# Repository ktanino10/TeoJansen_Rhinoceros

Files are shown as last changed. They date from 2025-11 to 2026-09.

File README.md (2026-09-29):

# Theo Jansen “Rhinoceros” — Ver.3.1 and prototype records

[English](README.md) | [日本語](README_ja.md)

**Website:** [English](https://ktanino10.github.io/TeoJansen_Rhinoceros/en/) · [日本語](https://ktanino10.github.io/TeoJansen_Rhinoceros/)

**Documents:** [English documents and Japanese counterparts](docs/README_en.md) · [How to use / resource legend](docs/USER_GUIDE_en.md). CAD and numerical data are shared; the original Ver.1 PDF drawings remain Japanese.

## Ver.3.1 — Current design

[Current comparison, 360° and 12-stage assembly](https://ktanino10.github.io/TeoJansen_Rhinoceros/en/r7.html) · [Continuous walking display and English videos](https://ktanino10.github.io/TeoJansen_Rhinoceros/en/walking.html) · [Current CAD / STEP / STL / BOM downloads](https://ktanino10.github.io/TeoJansen_Rhinoceros/en/index.html#downloads)

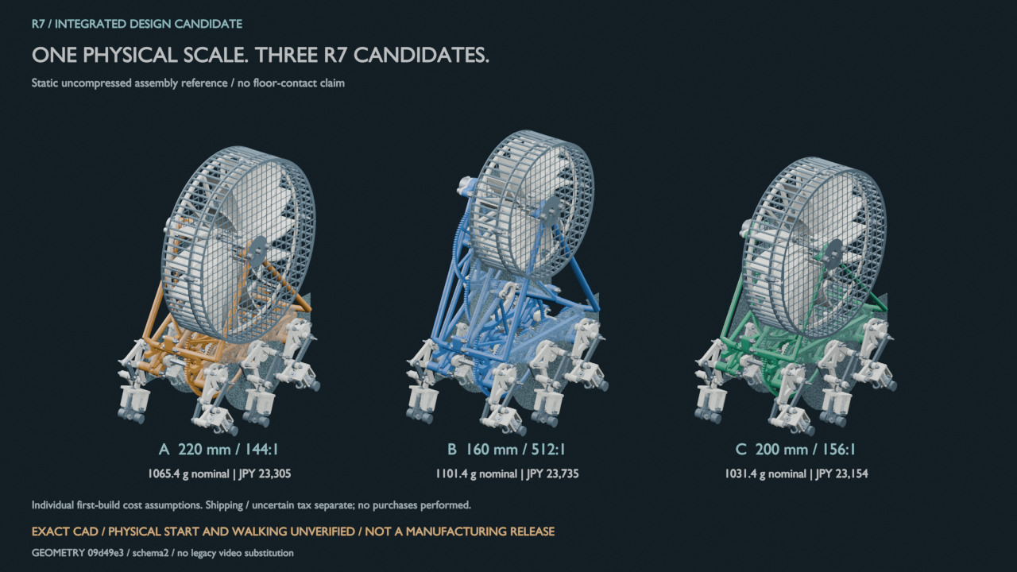
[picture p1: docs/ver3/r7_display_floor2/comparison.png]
Ver.3.1 floor-corrected A, B and C at the same scale; CAD rendering, not a physical build


**Ver.3.1 is the public name of the existing floor-corrected design, not a new mechanical revision.** Engineering ID: `v3-integrated-walkers-r7-16-floor2`; immutable artifact/source commits and hashes remain in [the source contract](site/r7-source.json). [Design and BOM index](docs/ver3/integrated_r7/README_en.md) · [Assembly](docs/ver3/integrated_r7/ASSEMBLY_en.md) · [Floor correction](docs/ver3/integrated_r7/FLOOR_CORRECTION_en.md) · [Separately versioned walking model](docs/ver3/r7_walking_v1/MODEL_en.md).

`manufacturingRelease=false`, physically qualified count 0; real wind, self-starting and physical 30 cm walking remain UNKNOWN. Seven representative slicing inspections are not whole-machine print/fit qualification. Walking uses prescribed 120 rpm input and 16× time compression, not measured performance. Existing r7 labels inside media refer to this Ver.3.1 geometry; canonical results, nulls and BOMs are unchanged.

**Version guide:** Ver.1/2 = historical physical builds; [Ver.3.0 = initial concepts, archived CAD and videos](https://ktanino10.github.io/TeoJansen_Rhinoceros/en/comparison.html); Ver.3.1 = current design. Internal r2/r3/r4/r6 study IDs are not public product versions. The build log below preserves the historical Ver.1/2 account.

---
## Repository Contents

```text
TeoJansen_Rhinoceros/
├── Fusion360/          # Fusion 360 design files (.f3d)
├── STL/                # 3D printable parts (STL files)
├── docs/               # Additional documentation and images
│   └── images/         # Photos and diagrams
├── README.md           # This file (English)
└── README_ja.md        # Japanese documentation
```



---

## Background

I first discovered Theo Jansen’s *Strandbeest* on YouTube and was captivated by the beauty of its wind-powered, organic motion.  
At the same time, I became fascinated by its internal mechanisms and thought: *“I want to try recreating this with my own hands.”*

Rather than making a perfect replica, I wanted to incorporate **more mechanical aesthetics and my own design preferences**.  
In particular, I love the design of the **ν (Nu) Gundam**, so I drew inspiration from its **color scheme** and **structural nuances** for this project.

For those unfamiliar with the Nu Gundam, here’s the official promotional video used as a design reference for part of this build:

<a href="https://youtu.be/TQ98cSiHVVs?si=otUml2E1TVQzA8v8" target="_blank">
  Nu Gundam official promo video thumbnail
</a>

---

## How to Use This Repository (Overview)

This “Rhinoceros” has evolved through multiple iterations from **Ver.1 to Ver.2**.  
While there is no fully detailed step-by-step manual, I believe you can build it by referencing the PDFs and animations below.

Each version includes the corresponding **STL files**.  
If you’re attempting this for the first time, I recommend starting by understanding the structure and motion of **Ver.1**.

I’ve also summarized my personal build log (as far as I can recall) in the following sections.

| Version | Summary | Drawings | Videos |
|---|---|---|---|
| Ver.1 | Initial design modeled in Fusion 360 | 1. [TeoJansen_2D_v1.pdf](./docs/テオヤンセン2Dv1.pdf)<br>2. [TeoJansen_2D_latest.pdf](./docs/テオヤンセン2D図面最新.pdf) | 1. [Assembly Video](https://youtu.be/Q7d0sq1SNJ0?si=nhAsBmjNhFsv74Ju)<br>2. [Motion Simulation](https://www.youtube.com/watch?v=RxUTcOTfPt0) |
| Ver.2 | Improved: 150% scale with more stable operation |  | 1. [First Motion Test](https://youtu.be/T3U7c1Mr3Y8?si=hUQZJXoczCW0qAUG)<br>2. [Overview / Re-verification](https://youtu.be/JzXOxTJvHzw?si=1MGZkGYogJQsFP-6) |

- **FYI**: This model is also published on Bambu Lab’s community platform [**MakerWorld**](https://makerworld.com/ja/models/1971139-n-gundam-style-strandbeest-ver-2).

---

# Ver.1 Build Process

## 1. Research
I observed YouTube videos and various images to infer and understand the structure and operating principles.  
Since many makers have shared their works worldwide, **web research and video viewing** are extremely helpful.

<a href="https://youtu.be/MYGJ9jrbpvg?si=qMYy9t26JGlFZo1x" target="_blank">
  Theo Jansen Strandbeest YouTube thumbnail
</a>

---

## 2. Design
All parts were 3D-modeled in Autodesk **Fusion 360**.  
In the early phase, I mainly traced shapes while closely observing real works;  
I performed little to no detailed mechanics calculations at that stage.

Because of that choice, I ended up iterating many rounds of prototyping and fine-tuning later—  
this became one of the most time-consuming and labor-intensive stages.  
Please treat the following drawing as **one reference among many**, not a strict blueprint.

### 📄 **Ver.1 2D Drawing**  
[TeoJansen_2D_latest.pdf](./docs/テオヤンセン2D図面最新.pdf)

> *Note:* GitHub may not preview PDFs inline. If so, please open them via the link above.

### 🎨 Ver.1 Concept Rendering (Fusion 360)

These are rendered images of Ver.1 in Fusion 360,  
created to verify geometry, structure, colors, and shading *before* actual printing—  
and to visualize the “moving art” concept during the design phase.

---

<div align="center">

| Oblique View | Front View | Side View |
|---|---|---|
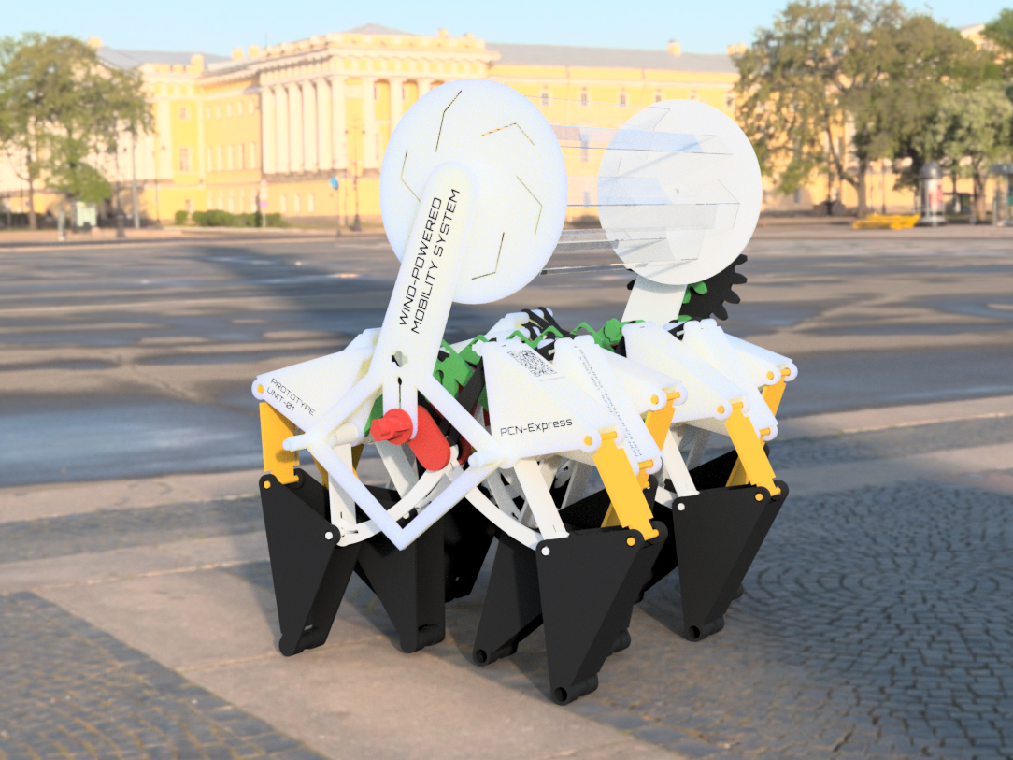
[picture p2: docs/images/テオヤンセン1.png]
Oblique view
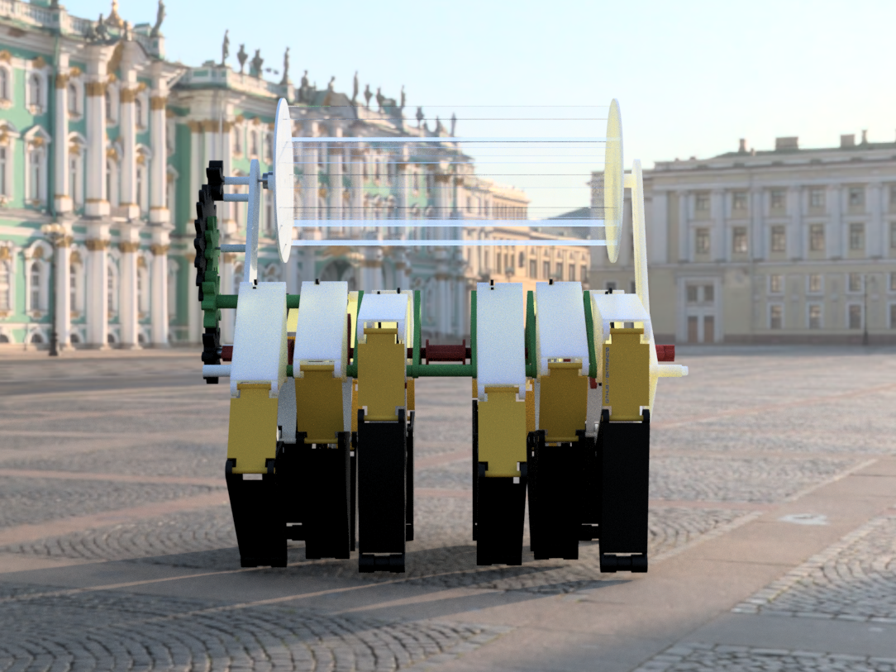
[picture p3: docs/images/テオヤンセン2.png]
Front view
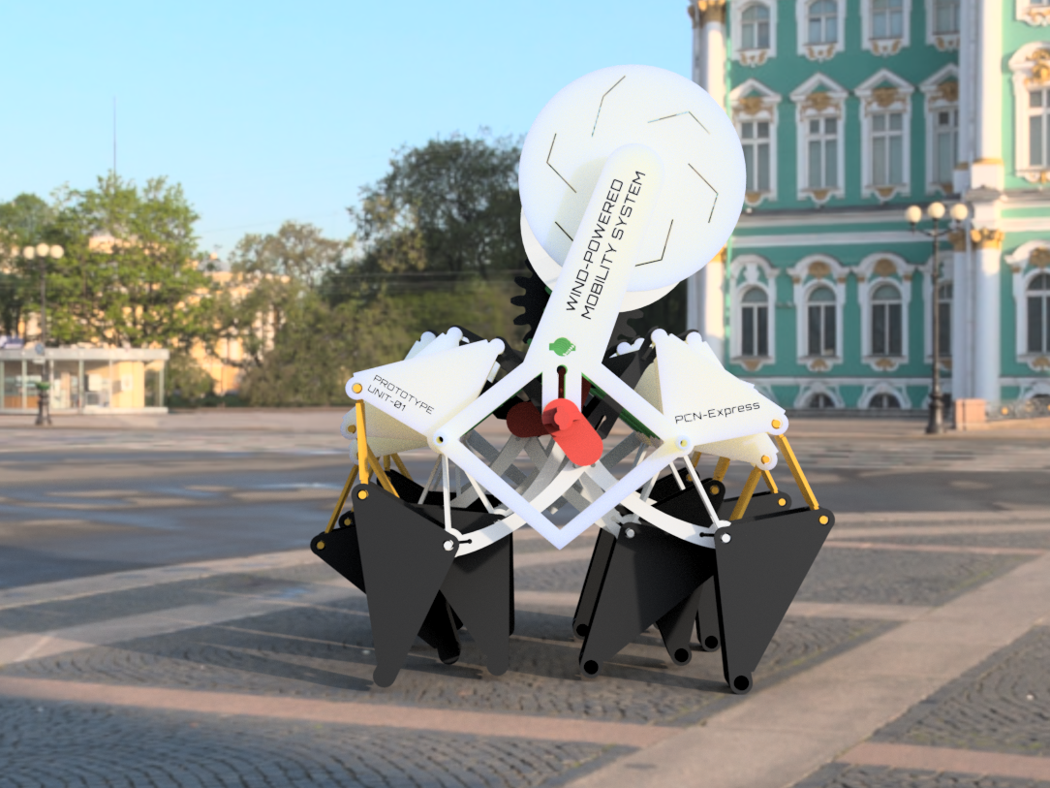
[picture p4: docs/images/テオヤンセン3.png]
Side view
|  |  |  |

| Rear View | Opposite Side | Reverse Oblique |
|---|---|---|
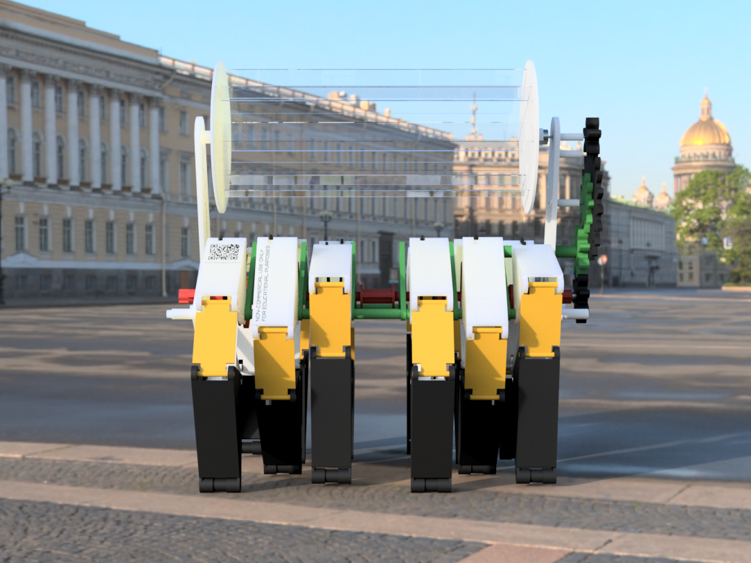
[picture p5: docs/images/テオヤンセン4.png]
Rear view
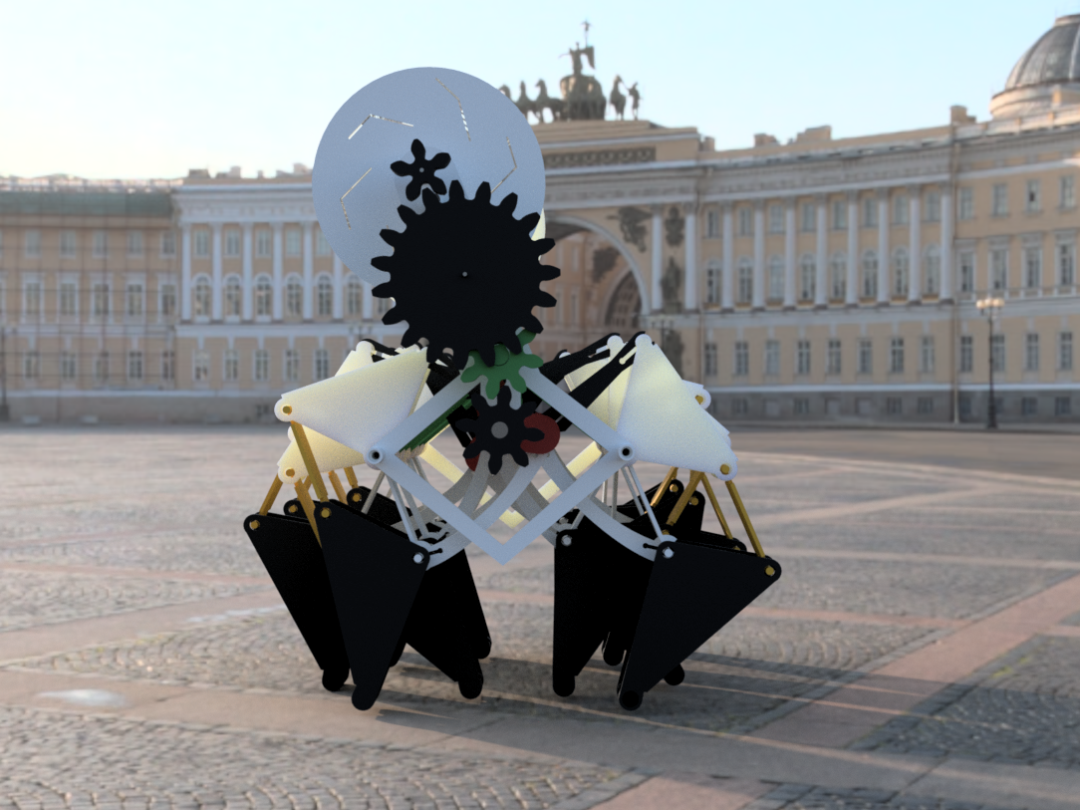
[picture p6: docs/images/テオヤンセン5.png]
Opposite side
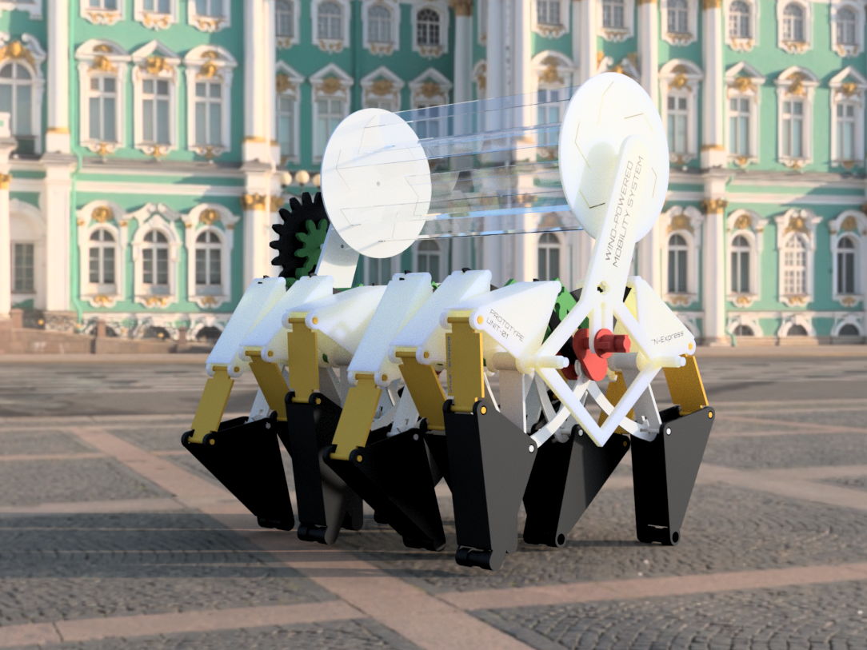
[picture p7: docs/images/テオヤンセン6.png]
Reverse oblique
|  |  |  |

</div>

### 🧩 Ver.1 Assembly Images  
[TeoJansen_2D_v1.pdf](./docs/テオヤンセン2Dv1.pdf)

> *Note:* If PDF preview doesn’t work on GitHub, please open via the link.

**Assembly Video**  
<a href="https://youtu.be/Q7d0sq1SNJ0?si=nhAsBmjNhFsv74Ju" target="_blank">
  Ver.1 Assembly video thumbnail
</a>

### 🦿 Ver.1 Motion Image  
**Simulation Video**  
<a href="https://youtu.be/RxUTcOTfPt0?si=KSsferuiFyFRqOAX" target="_blank">
  Ver.1 Motion Simulation thumbnail
</a>

---

## 3. 3D Printing
I optimized print directions and part splits to balance dimensional accuracy and strength.

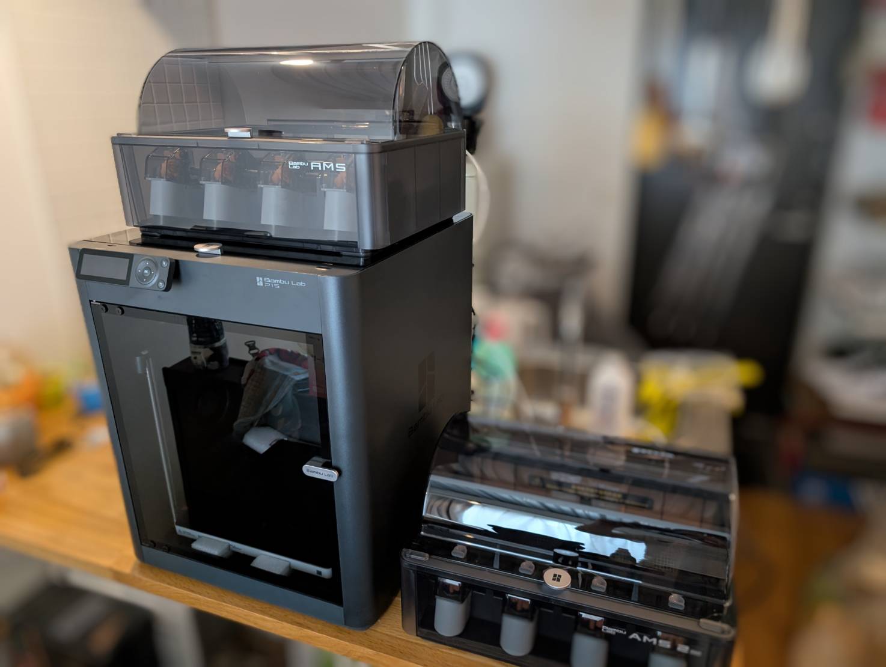
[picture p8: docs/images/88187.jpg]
3D printer in progress


## Recommended Print Settings

- **Scale**: 150% (legs recommended at 160%)  
- **Material**: ABS (also common for Gunpla; heat resistance ~80 °C)  
- **Printer**: Bambu Lab FDM printer  
- **Note 1**: This model is also listed on [**MakerWorld**](https://makerworld.com/ja/models/1971139-n-gundam-style-strandbeest-ver-2).  
- **Note 2**: Depending on geometry, consider **splitting parts and bonding afterward**.  
  Although support is an option, considering **cost and time**, I mainly chose splitting (support kept minimal) except for the crankshaft.

---

🎥 ** Print Video**  
Watch on YouTube (https://www.youtube.com/watch?v=6YfYPoaMa58)

---

## 4. Sanding
Surfaces that contact supports tend to be rough, so I sanded the crankshaft with a power sander.  
By stepping through **#400 → #600 → #800**, I smoothed layer lines for a clean finish.

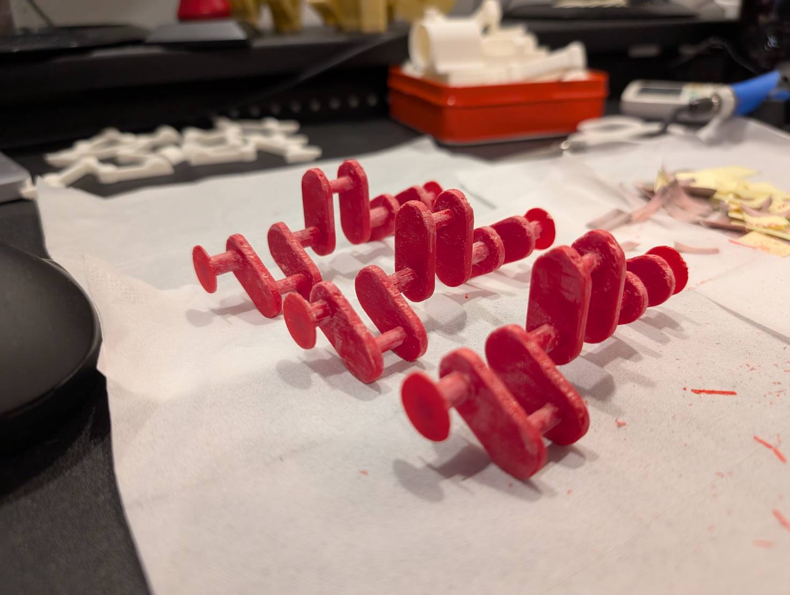
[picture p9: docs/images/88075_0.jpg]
Crankshaft after sanding


🎥 **Sanding Process**  
Watch on YouTube (https://www.youtube.com/watch?v=w-jB8-OUFfA)

---

## 5. Ultrasonic Cleaning
After sanding, I cleaned parts with an **ultrasonic cleaner**.  
Adding a **small amount of detergent** reduces surface tension so bubbles penetrate details and remove fine dust and swarf.

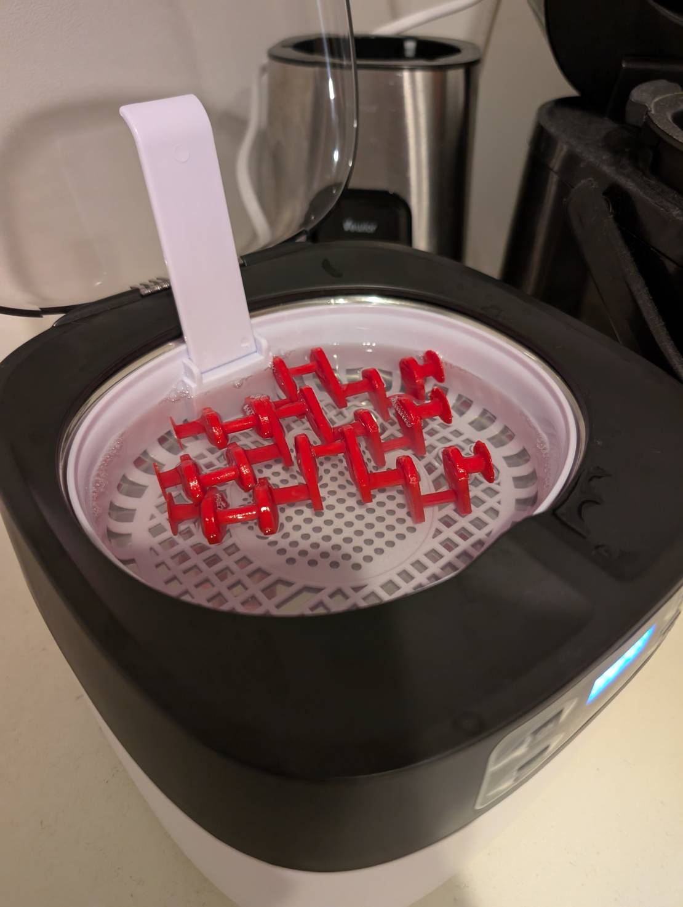
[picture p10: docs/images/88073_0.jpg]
Ultrasonic cleaning


🎥 **Ultrasonic Cleaning Video**  
Watch on YouTube (https://www.youtube.com/watch?v=2DyWBz1phlA)

### 🧴 Bonding After Cleaning
Some parts require **temporary sub-assembly by bonding** after cleaning.  
I used the following adhesive, which bonds ABS strongly and maintains strength after curing:

- **Adhesive**: [Tamiya ABS Cement](https://www.tamiya.com/japan/products/87137/index.html)  
  (Part no. 87137 / 40 ml)

> *Tip:* Waiting about 30 minutes for full cure improves joint stability.

---

## 6. Painting
I airbrushed the parts in a paint booth. Equipment used:

- Airbrush  
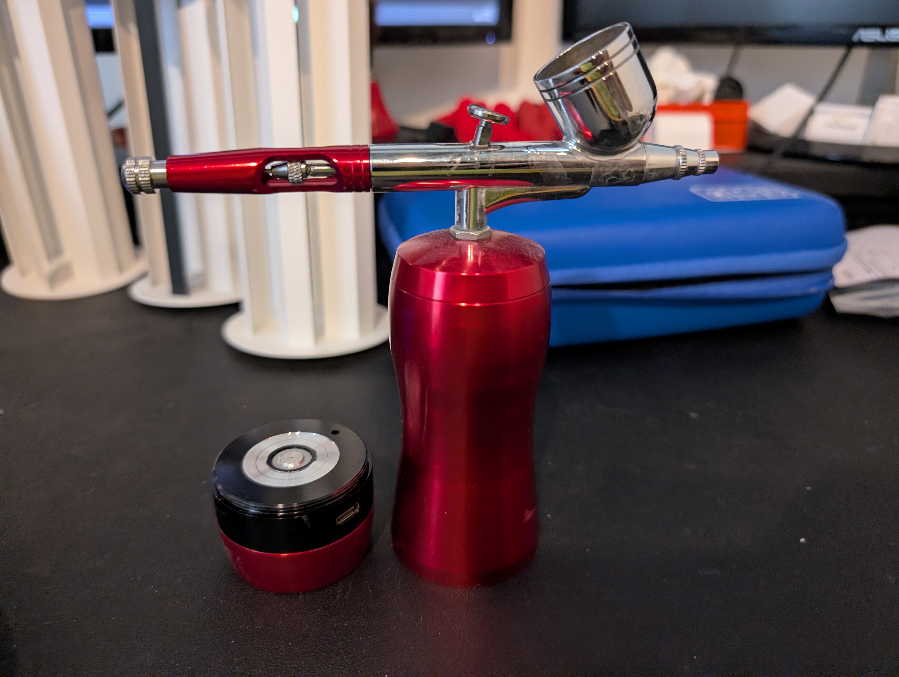
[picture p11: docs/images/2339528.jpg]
Airbrush used
  

- Spray booth  
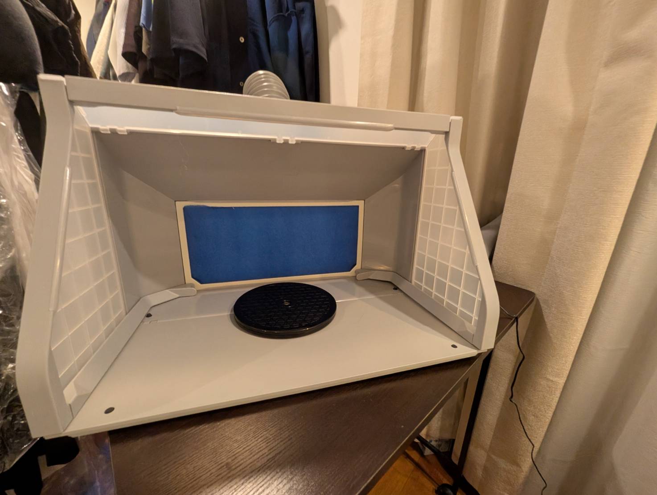
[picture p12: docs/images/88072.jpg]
Spray booth used
  

- For safety, I wore a respirator.  
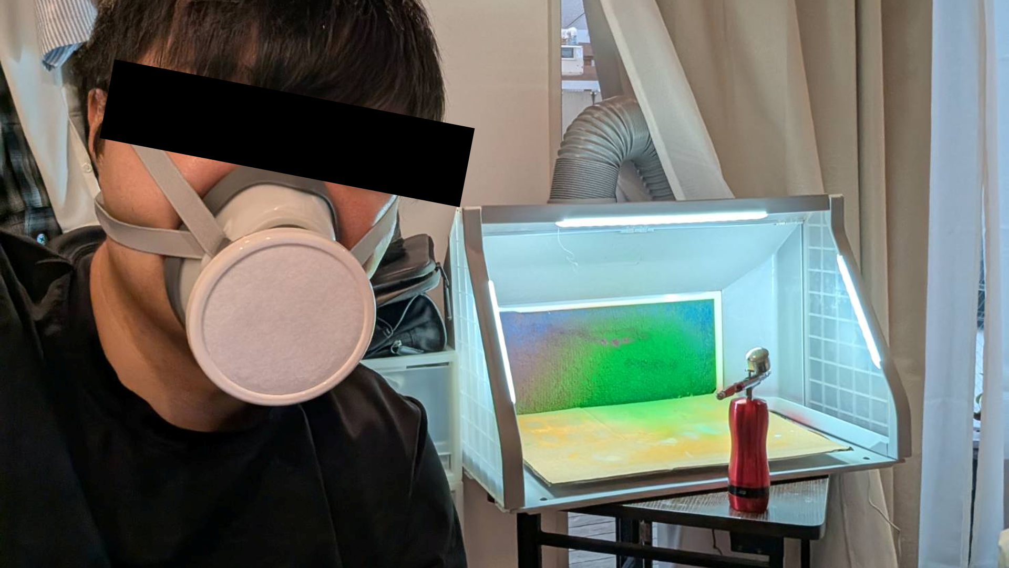
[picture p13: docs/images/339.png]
Respirator mask


- Prep image before painting  
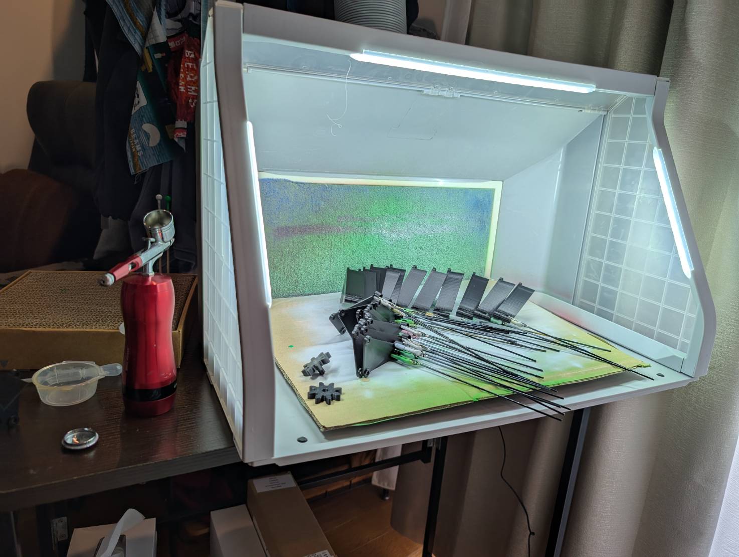
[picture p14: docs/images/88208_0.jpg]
Painted parts
  

### 🎨 Painted Parts
Below are comparisons of pre-/post- sanding, ultrasonic cleaning, and painting.

- Drying painted parts  
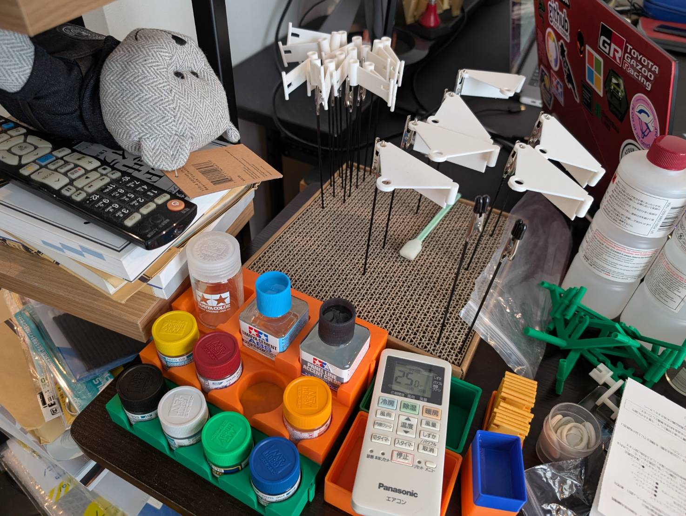
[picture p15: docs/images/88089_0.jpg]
Painted parts drying
  

- Crankshaft finish comparison  
  Left = before processing; Right = after sanding/cleaning/paint.

| View | Left (before: no sanding/cleaning/paint) • Right (after: sanding/cleaning/paint) |
|---|---|
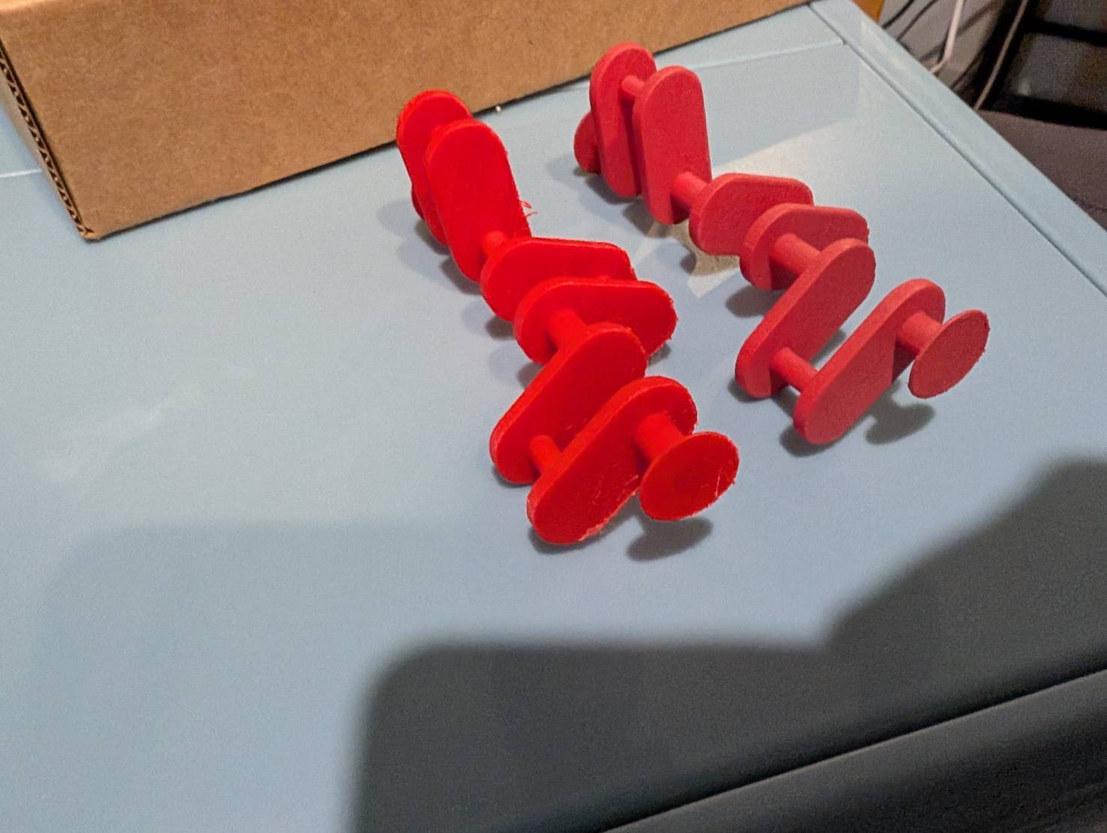
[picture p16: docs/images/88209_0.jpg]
Crankshaft comparison oblique - before
| **Oblique** |  | Crankshaft comparison oblique - after |
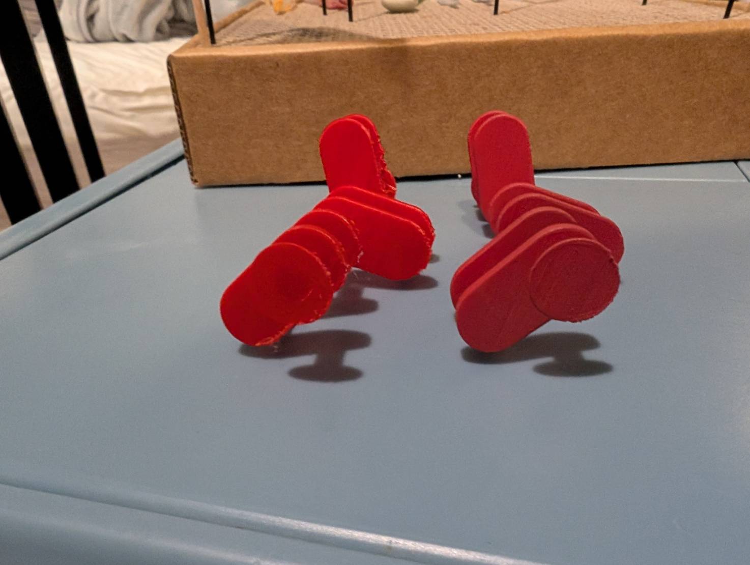
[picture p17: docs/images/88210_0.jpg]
Crankshaft comparison side - before
| **Side** |  | Crankshaft comparison side - after |
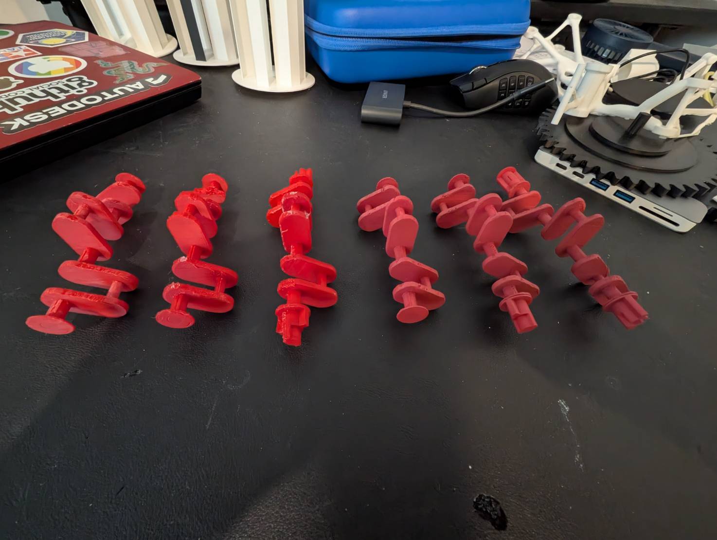
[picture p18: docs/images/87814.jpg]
Crankshaft comparison gradient - before
| **Gradient finish** |  | Crankshaft comparison gradient - after |

---

## 7. Decals
I applied decals with a setting solution, adjusted positions with cotton swabs,  
and finished with a matte topcoat to enhance depth and definition in the details.

### 📸 Decal Application
Below are images taken during and immediately after application:

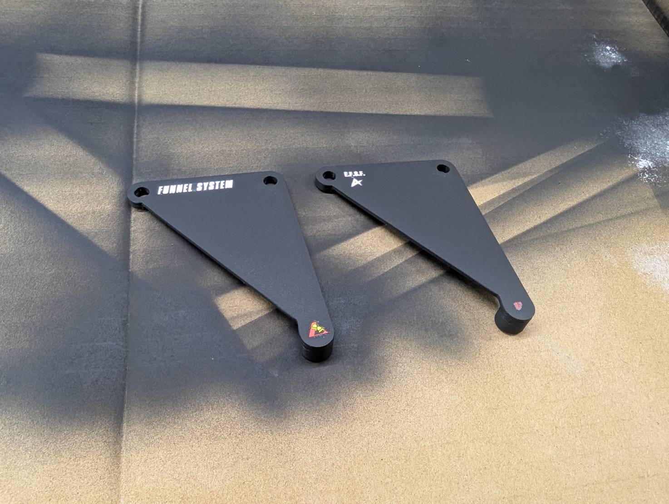
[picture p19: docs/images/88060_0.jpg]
Decal work 1
  
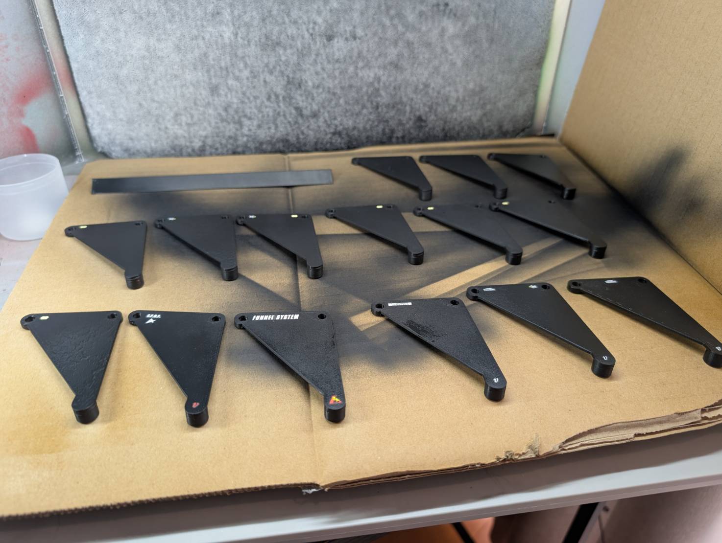
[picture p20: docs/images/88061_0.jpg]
Decal work 2
  
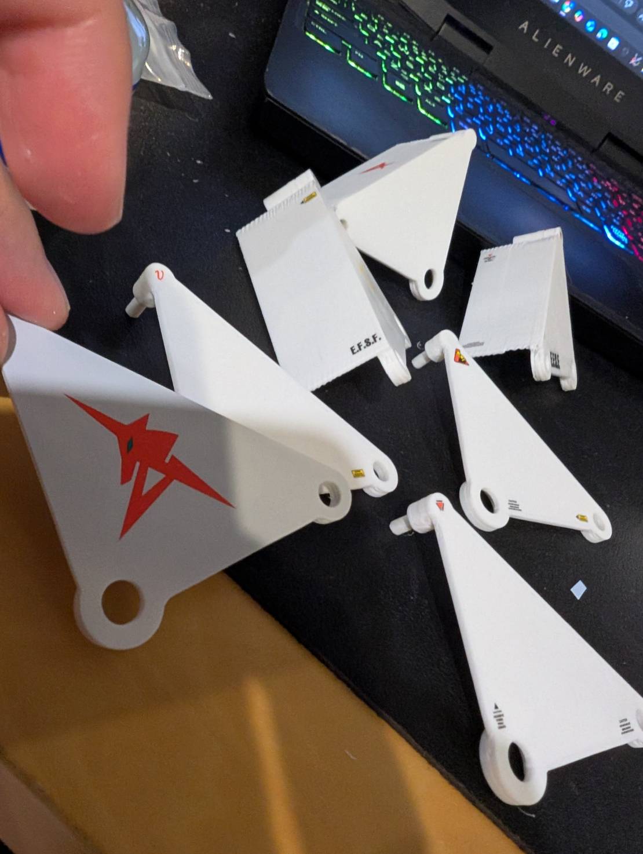
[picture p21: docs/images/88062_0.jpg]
Decal work 3
  
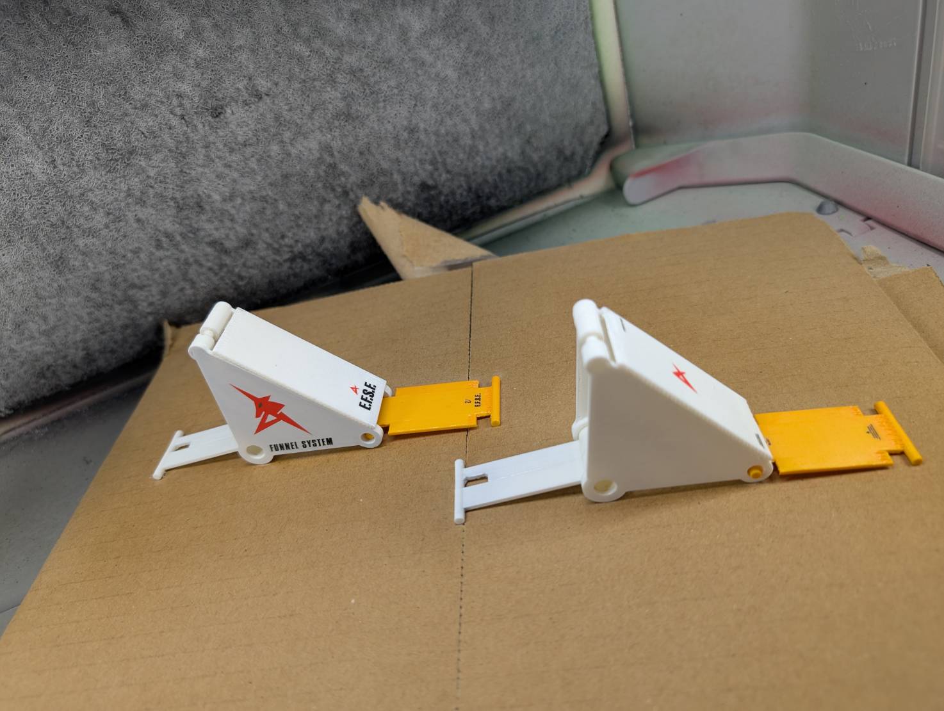
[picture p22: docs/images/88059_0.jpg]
Decal work 4


---

## 8. Ver.1 Final Assembly & Functional Check

I verified gear transmission, crankshaft rotation, and wind-driven motion.  
While aiming for smooth operation overall, several issues were discovered.

For the wind turbine and gear shafts, I used **stainless steel round rods**  
and cut them to length with **metal shears**:

- [Stainless steel rods (Amazon)](https://www.amazon.co.jp/dp/B0FCYMZJF7?ref=ppx_yo2ov_dt_b_fed_asin_title&th=1)  
- [Metal shears (Amazon)](https://www.amazon.co.jp/dp/B0BQB8PLWK?ref=ppx_yo2ov_dt_b_fed_asin_title)

### Ver.1 Exterior (at completion)

<div align="center">

| Oblique | Front | Side |
|---|---|---|
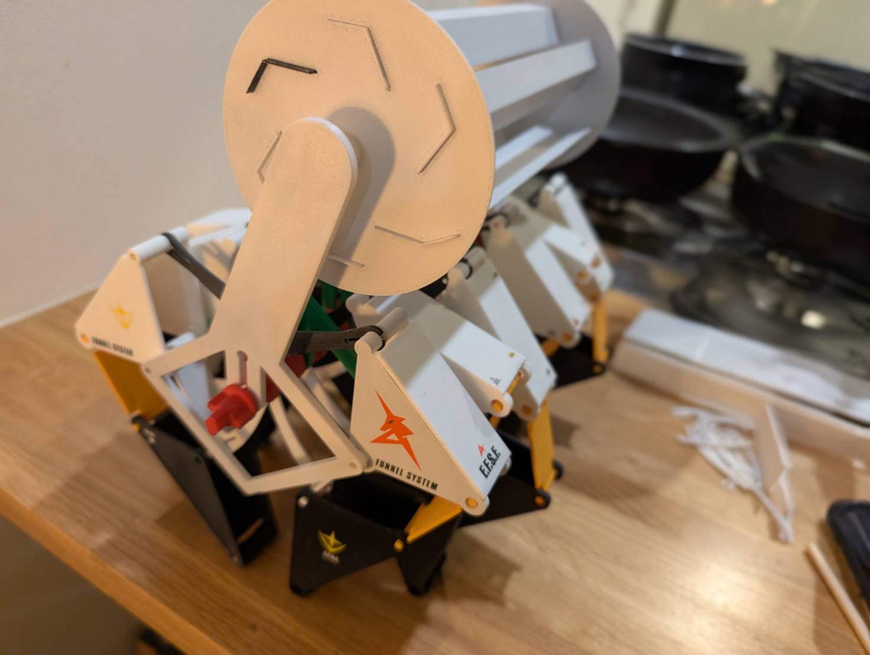
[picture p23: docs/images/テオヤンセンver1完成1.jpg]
Ver1 oblique
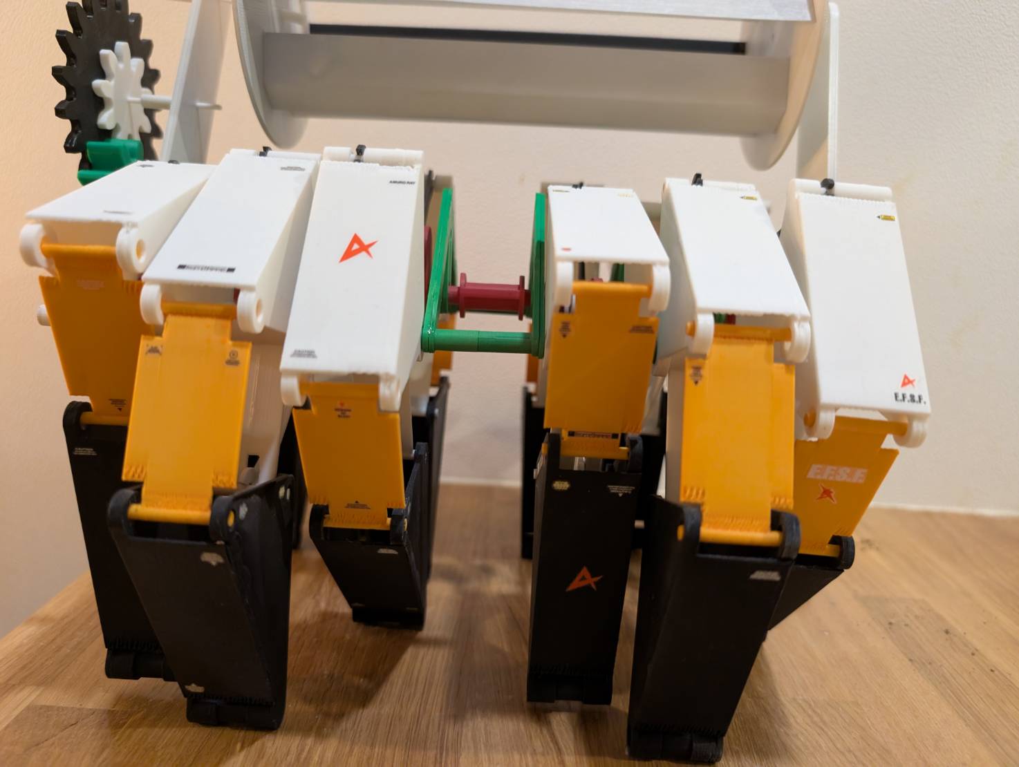
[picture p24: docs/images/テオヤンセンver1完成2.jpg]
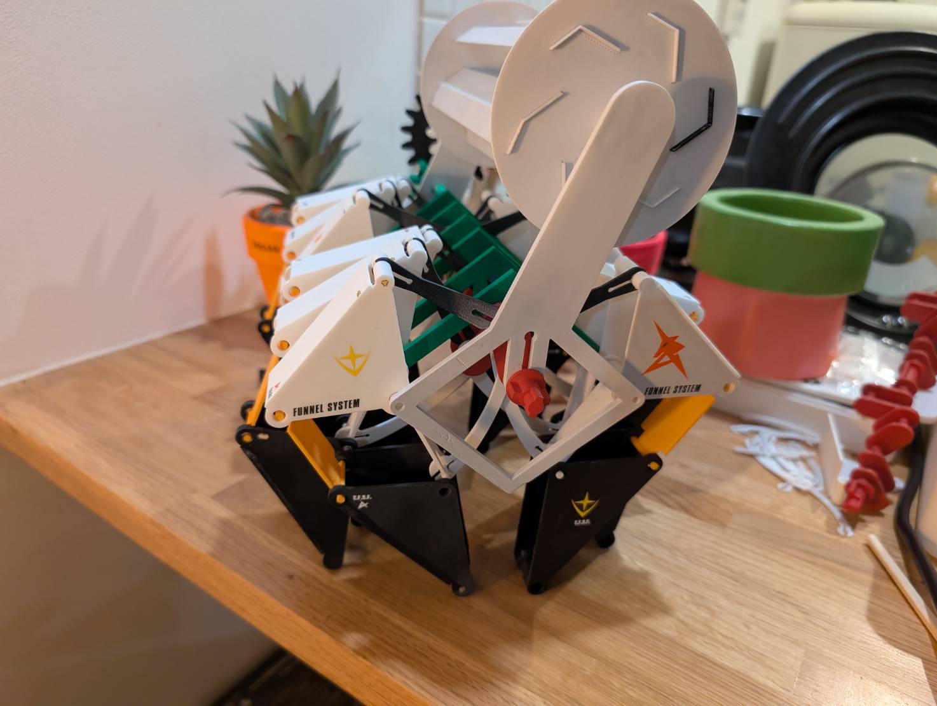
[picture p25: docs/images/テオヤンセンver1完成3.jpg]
|  |  |  |

| Rear | Opposite Side | Reverse Oblique |
|---|---|---|
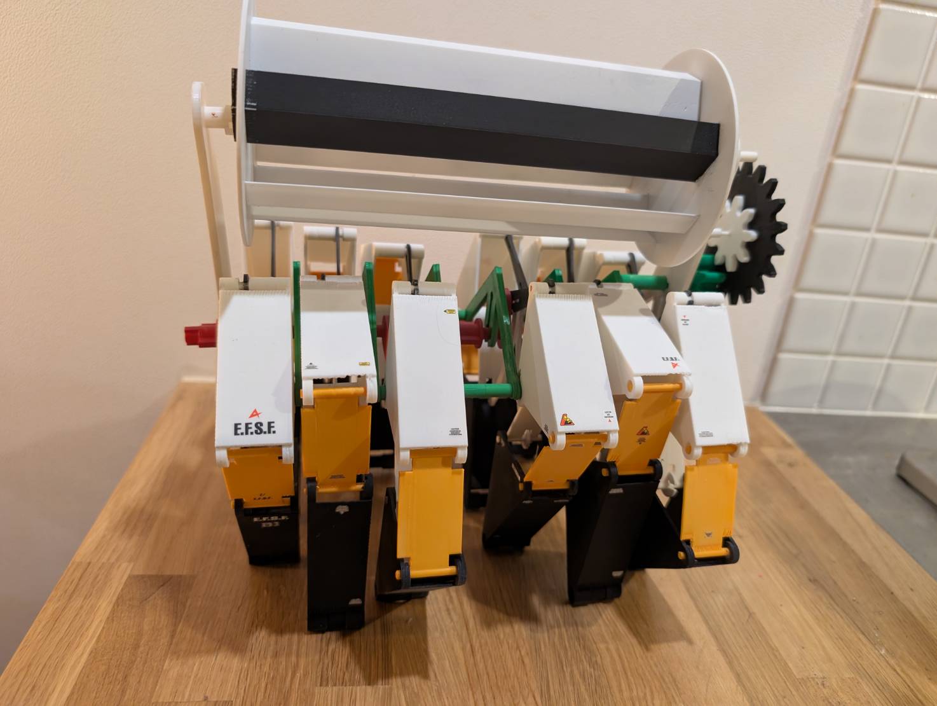
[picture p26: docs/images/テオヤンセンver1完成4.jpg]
Ver1 rear
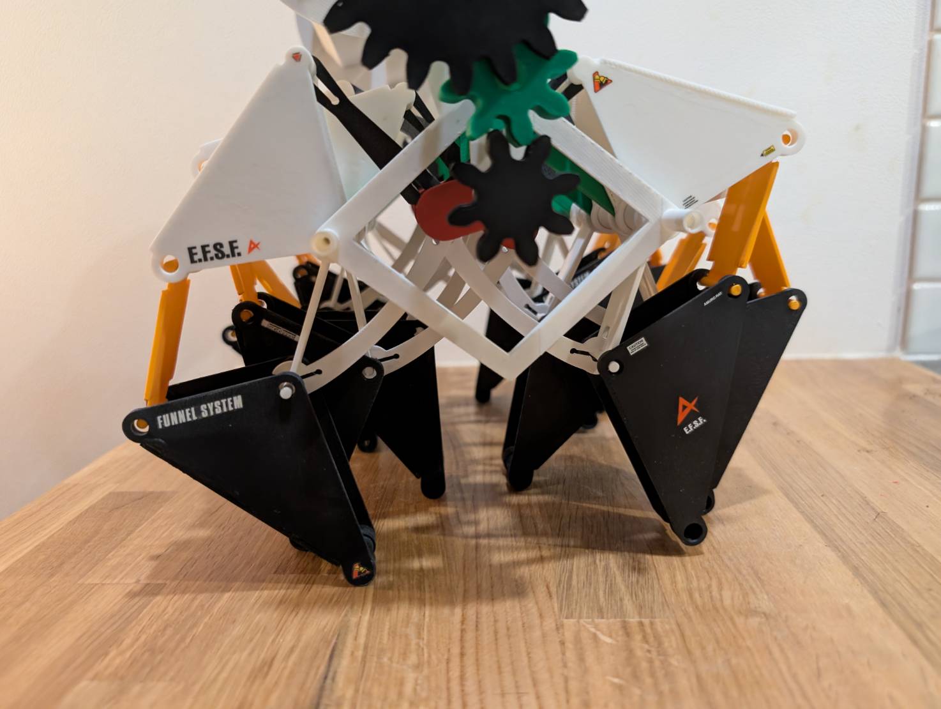
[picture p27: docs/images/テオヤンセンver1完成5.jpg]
Ver1 opposite
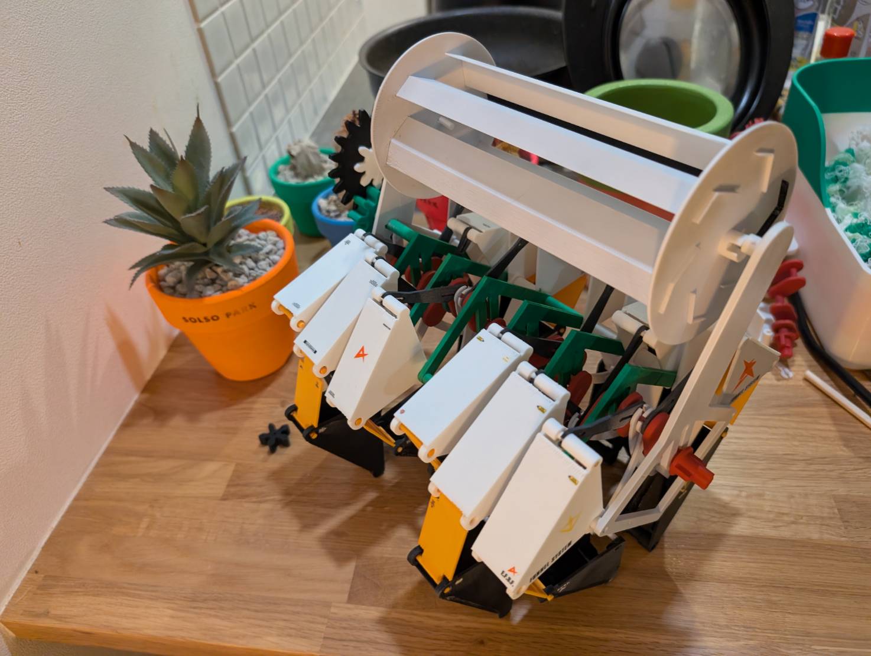
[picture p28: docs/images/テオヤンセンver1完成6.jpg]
Ver1 reverse oblique
|  |  |  |

</div>

### ⚙️ Observed Issues

- The wind turbine did not rotate well under wind power.  
- Some parts popped off during manual rotation.  
- The turbine was unstable and the shaft exhibited wobble.

These findings became key drivers for improvements in Ver.2.

🎥 **Initial Motion Test Video**  
Watch on YouTube (https://youtu.be/Ic3GasmMlio?si=MSvn6-1x6faBUwIh)

---

## 9. Ver.1 Redesign & Structural Improvements

### ⚙️ Main Causes of Ver.1 Failures and Directions for Improvement

Several issues surfaced during Ver.1 prototyping.  
Below are the causes and how I addressed them toward Ver.2.

1) **Gear Ratio Insufficiency**  
The **gear ratio was too small** relative to the crankshaft, yielding insufficient torque from wind power and unstable rotation.

Taking a cue from bicycle gearing (trade-off between force and speed),  
I redesigned the gear train with large–small gear pairs that transmit torque more effectively,  
so the system can move even with low wind input.

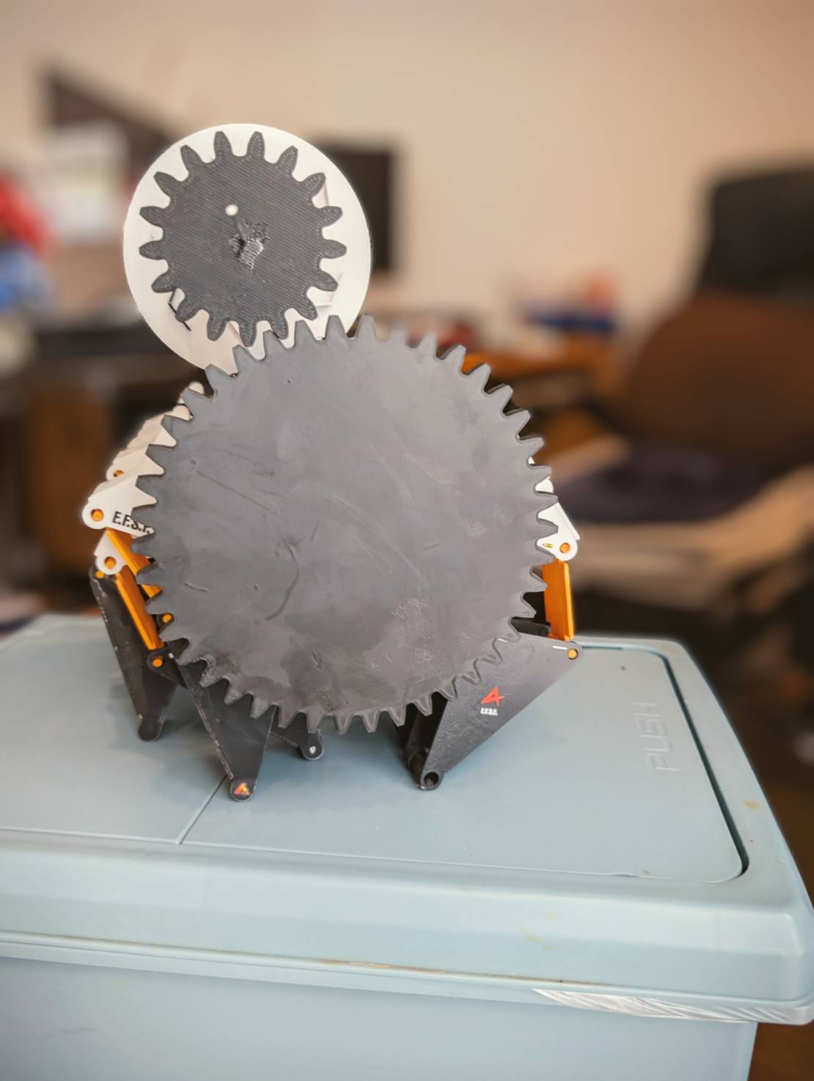
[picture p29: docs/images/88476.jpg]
Gear test 1


> The photo above is an example of ratio tests toward Ver.2.  
Even a simple combination matters when you’re figuring out how to transmit and amplify small forces.

Because gears are **highly modular and combinable**, I explored many patterns for Ver.2:

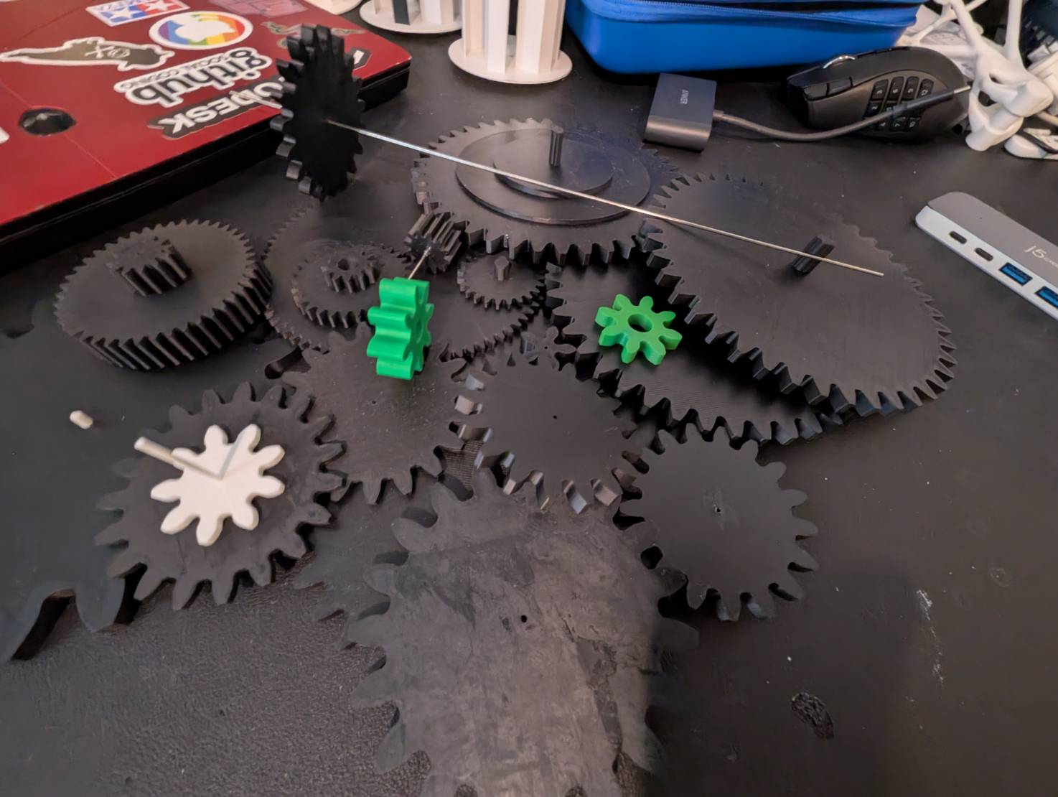
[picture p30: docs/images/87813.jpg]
Series of gear prototypes


> Through repeated prototyping, I gradually appreciated how deep gear design can be—  
and my room ended up filled with gears.

2) **Inefficient Turbine Geometry**  
The initial **six-blade turbine** did not capture enough wind; torque was lacking.  
A chance observation of a very efficient garden turbine led me to realize it’s not only about *catching* wind but also **how to let it pass and harmonize** with the flow.  
I thus adopted the **Savonius** type, which stabilizes rotation using differential drag.

Watch on YouTube (https://youtube.com/shorts/n7MyLVN-XGA)

3) **Shaft Deflection (Stainless Rod)**  
The thin stainless rod **deflected**, causing unwanted friction and rotational wobble.  
I extended/reinforced supports so the rod stays **level**, reducing wobble and friction losses.

4) **Hook Disconnecting from Crankshaft**  
The hook that drives the legs often popped out because there was **no structure to resist the force vector** in the direction of disengagement.  
I added a supporting surface aligned with the force direction, significantly improving connection stability.

---

## 10. Ver.2 Completion & Review

### Ver.1 vs Ver.2 — Key Improvements

After revisiting each issue, structural rigidity and operational stability improved significantly.  
Below are the main differences:

| Item | Ver.1 (Initial) | Ver.2 (Improved) |
|---|---|---|
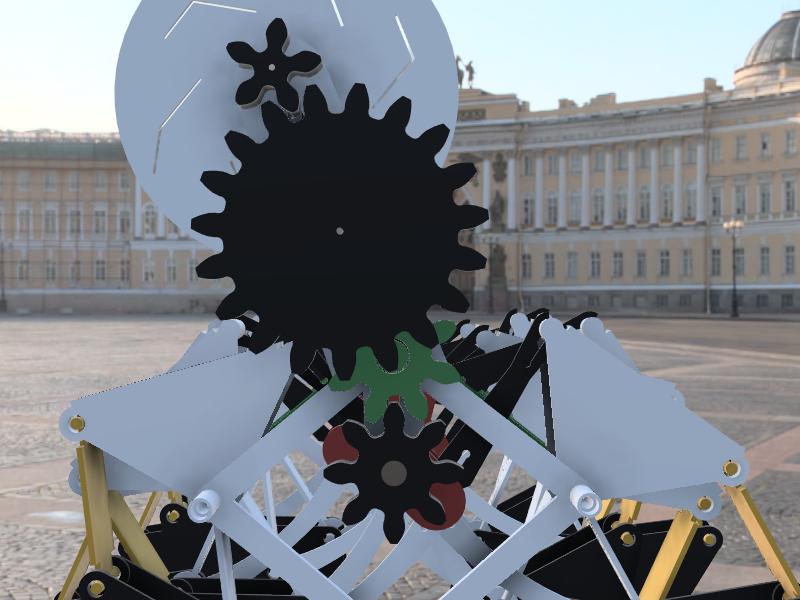
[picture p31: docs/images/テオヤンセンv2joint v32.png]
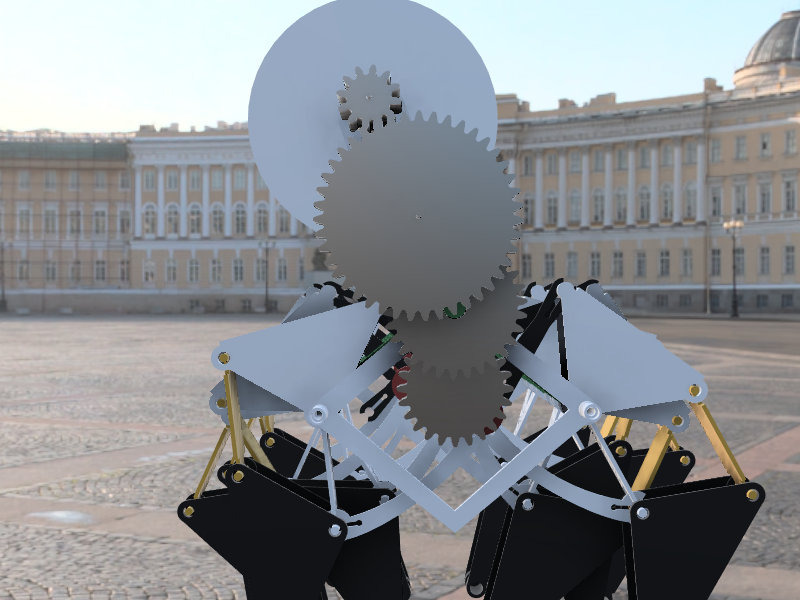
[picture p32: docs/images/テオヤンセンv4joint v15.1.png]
| **Front View** |  |  |
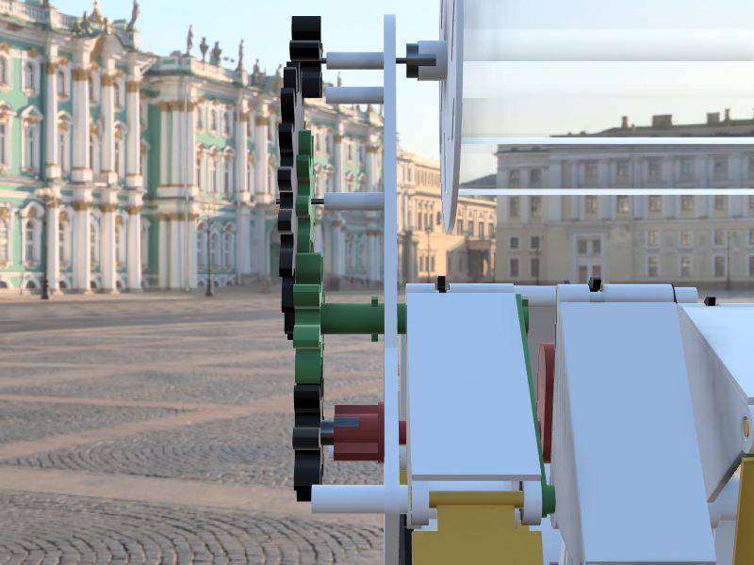
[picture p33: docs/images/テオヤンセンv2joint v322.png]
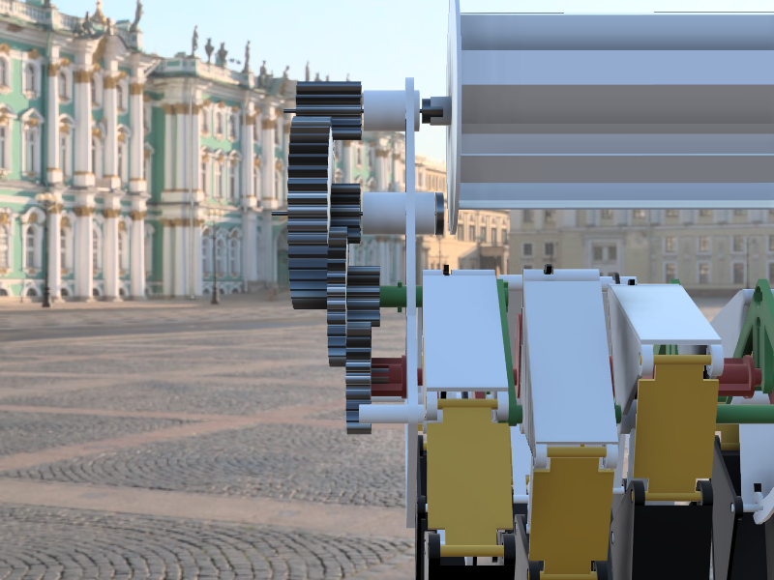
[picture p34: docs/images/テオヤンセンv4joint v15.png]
| **Side View** |  |  |
| **Gear Ratio** | Too small; insufficient torque under wind. | Redesigned ratios; runs stably with lighter wind. |
| **Gear Accuracy** | Thickness/pitch uneven; meshing losses. | Refined tooth profile; smoother rotation, lower friction. |
| **Structural Stability** | Weak shaft support; stainless rod deflected. | Extended/reinforced supports; **deflection issue mitigated**. |
| **Crank Layout** | Inefficient force paths; uneven leg motion. | Repositioned with force vectors in mind; smoother drive. |
| **Design** | Rough experimental look. | Balanced **mechanical aesthetics** and function. |

---

### Six-Blade vs. Savonius—Geometry Comparison

Below compares Ver.1 (six-blade) and Ver.2 (Savonius).  
In Ver.2, wind capture and torque transmission were reworked for stable rotation.

| View | Left (Ver.1) • Right (Ver.2) |
|---|---|
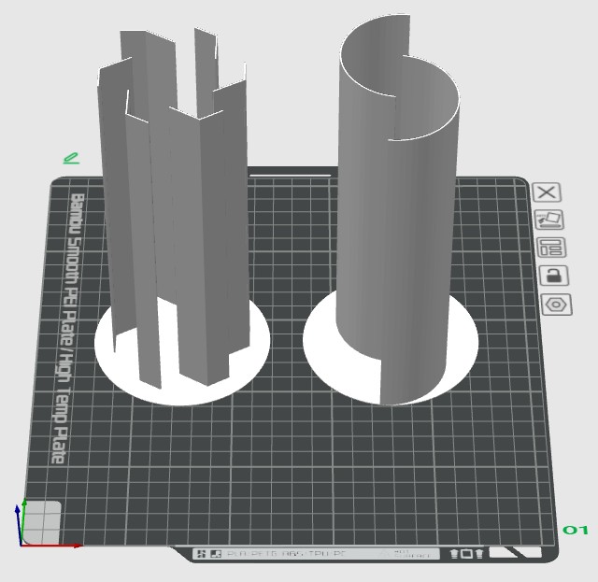
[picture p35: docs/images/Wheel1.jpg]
Six-blade front
| **Front** |  | Savonius front |
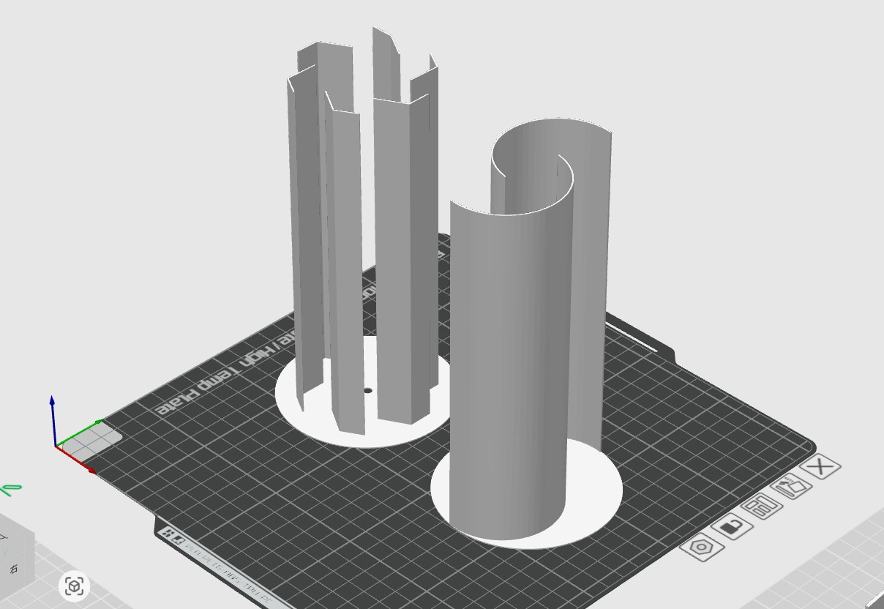
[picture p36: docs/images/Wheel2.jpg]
Six-blade oblique
| **Oblique** |  | Savonius oblique |
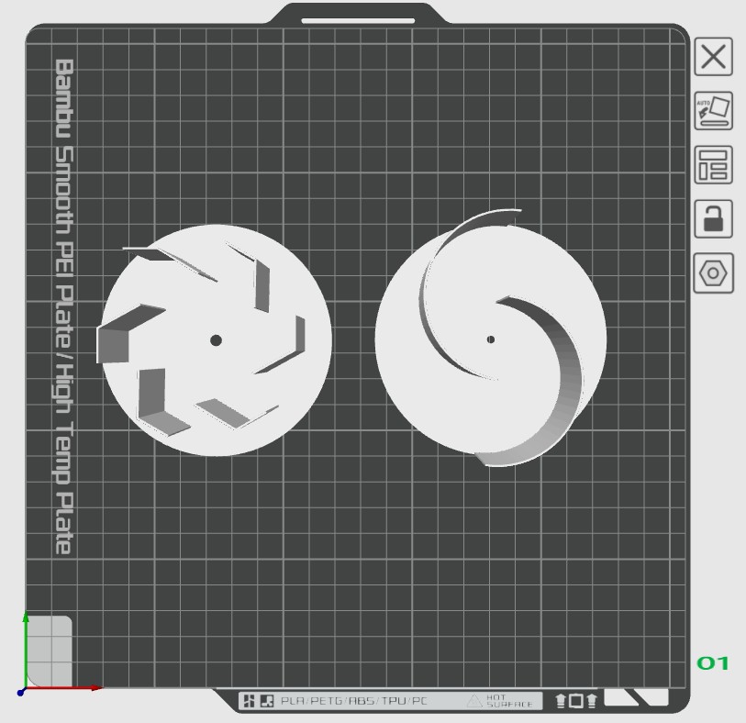
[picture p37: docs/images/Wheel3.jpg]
Six-blade top
| **Top-down** |  | Finish gradient |

**Real prototypes (Left: six-blade / Right: Savonius)**  
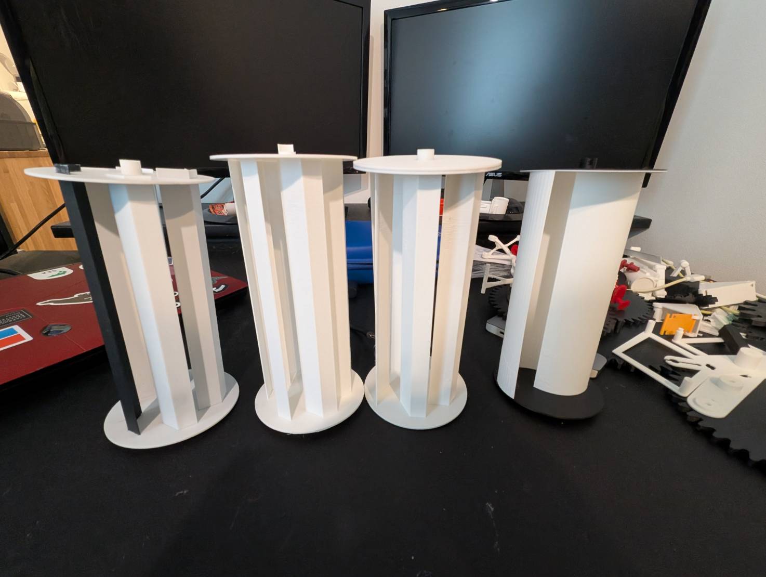
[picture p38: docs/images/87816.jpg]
Real turbine comparison


Why Savonius performed better:

| Aspect | Six-Blade (Ver.1) | Savonius (Ver.2) |
|---|---|---|
| **Wind Interaction** | Strong head-on capture but large counter-drag on the rear. | Cup geometry channels flow while concentrating drag in the rotation direction. |
| **Torque** | Poor starting torque in low wind. | Differential drag enables easy start in weak wind. |
| **Stability** | Sensitive to wind direction; balance easily disturbed. | One cup receives wind while the other sheds it; stable rotation. |
| **Tuning** | Blade angle/shape optimization is tricky. | Simpler, more repeatable structure. |
| **Overall** | Visually light but low wind-use efficiency. | Balanced torque and stability; adopted as final form. |

---

### Hook–Crank Connection (Improvement)

In Ver.1, the **leg-drive hook** often popped out because the **force vector** aligned with the disengagement direction and nothing resisted it.  
In Ver.2, I added a **supporting surface** to accept that force direction and redesigned the hook geometry, greatly improving reliability.

| View | Left (Ver.1) • Right (Ver.2) |
|---|---|
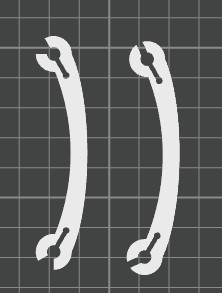
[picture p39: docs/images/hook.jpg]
Hook comparison 1
| **Hook (1)** |  |
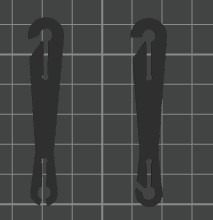
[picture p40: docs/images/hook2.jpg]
Hook comparison 2
| **Hook (2)** |  |

---

### Ver.2 Exterior

<div align="center">

| Oblique | Front | Side |
|---|---|---|
| Ver2 oblique | Ver2 front | Ver2 side |

| Rear | Opposite Side | Reverse Oblique |
|---|---|---|
| Ver2 rear | Ver2 opposite | Ver2 reverse oblique |

</div>

---

### Ver.2 Motion Videos

Here’s the moment it **first moved in real life**:

🎥 **Initial Motion Test**  
Watch on YouTube (https://youtu.be/T3U7c1Mr3Y8?si=hUQZJXoczCW0qAUG)

🎥 **Overview / Re-verification**  
Watch on YouTube (https://youtu.be/JzXOxTJvHzw?si=1MGZkGYogJQsFP-6)

**Summary**  
Ver.1 focused on *materializing the idea* and left room for improvement in gears and crank layout.  
Ver.2 rebuilt the mechanical balance, evolving into a **Rhinoceros that walks naturally on wind power alone**.

---

## 🌬️ What’s Next

For **Ver.3**, I aim for even more natural walking.  
I’ll take a short break to organize my learnings, then pursue the following improvements:

### 💡 Planned Improvements

- **Generative Design (GD)**  
  Using Autodesk **Fusion 360** generative design to optimize structural strength, weight, and stiffness balance.  
  This approach leaves material only where necessary, enabling **maximum stiffness at minimum mass**.

  Below are early experiments I tried:

  <div align="center">

  🧠 **GD in progress**  
  GD design process

  ⚙️ **Comparison (Top: GD candidate / Bottom: Ver.2)**  
  GD vs Ver2

  </div>

  Also, practical applications of GD have progressed in industry—  
  for example, initiatives by Isuzu Central Research Laboratory (Autodesk official blog):  
  [Isuzu Central Research Laboratory × Generative Design](https://www.autodesk.com/products/fusion-360/blog/isuzu-central-research-laboratory-generative-design/)

---

- **Reducing Shaft Deflection**  
  In Ver.2, I used a thin stainless rod as a rotating shaft, which caused **deflection** (elastic bending), friction losses, and wobble.

  Based on **Young’s modulus (E)** and beam bending behavior, slender members have larger displacement under load.  
  I’m considering the following:

  - Switch to **larger-diameter lightweight hollow shafts** (e.g., carbon tube or aluminum alloy).  
  - Add **intermediate supports (support bearings)** to distribute deflection.  
  - Improve **coaxiality** between shaft and gears to increase torque transmission efficiency.

  These should increase **shaft rigidity (E×I)** and **reduce friction losses** for more stable operation.

---

- **CFD Visualization of Wind Energy**  
  I plan to use **CAE** tools to simulate the energy transfer from turbine blades to the crank mechanism via **CFD**.  
  I’ll analyze how **vortices and pressure distributions** vary with wind speed, blade angle, and Savonius geometry,  
  and quantitatively visualize torque generation—explaining physically **why “letting wind pass” yields stable rotation**.

---

## Reflections

Through this project, I deeply felt the fusion of **Theo Jansen’s philosophy and engineering**.  
Building everything by myself from “1” was challenging enough—and it made me appreciate even more that he started this from “0”.

Designing and fabricating the crankshaft and gears gave me hands-on insight into the depth and versatility of mechanical components—  
it felt like relearning the fundamentals of mechanical engineering through practice.  
Even in the journey toward Ver.3, I realized that *making a Strandbeest* itself becomes a gateway to learning across disciplines.

Harnessing wind—nature itself—to drive a kinetic sculpture truly sits at the **intersection of engineering and art**.  
The blend of function and beauty, design and sensibility, was an inspiring and invaluable experience for me.

I hope to continue sharing this project in education, exhibitions, and creative contexts.  
If you have ideas or suggestions, I’d love to hear them.

---

## 🧩 Extras

When I wanted to **batch-export multiple Fusion 360 components to STL**,  
I couldn’t find a GUI method—so I created a small **Fusion API add-on button**.

I implemented the coding smoothly with **GitHub Copilot**.  
If you haven’t tried Copilot yet, I highly recommend it—  
it speeds up development and broadens your creative options. 🚀

🔗 [Reference repo: Fusion360 Export All STL – Add-on Project](https://github.com/ktanino10/fusion360-export-all-stl/blob/main/README.md)

---

📘 **Japanese version:** [README_ja.md](./README_ja.md)

🦏 **Happy Building & Learning!**

---

## Ver.3.0 — Initial engineering concepts (archive)

> Historical first cut, **not the current design or recommended current download**. “Ver.3” in the original documents below means this Ver.3.0 package. Use [Ver.3.1 current design and downloads](https://ktanino10.github.io/TeoJansen_Rhinoceros/en/index.html#ver3) for the floor-corrected geometry.

**This first-cut package includes real FreeCAD/STEP assemblies, custom printable parts, BOMs, assembly instructions and Blender visualizations. It is not a manufacturing release or a demonstration of autonomous wind-powered walking.**

The confirmed failure was **slip at the turbine/gear-to-shaft joint**, not proven bearing seizure. The new load path uses metal 8 mm REX shafts and form-fitting metal hubs, bolted printed components, explicit axial retention, inner-ring spacers and removable guards. A collar is not treated as a torque key.

Archived Ver.3.0 designs at a common physical scale

| Design | Rotor diameter × span | Drivetrain | CAD and parts |
|---|---:|---|---|
| **A — Large rotor** | 300 × 180 mm | Purchased 2:1 toothed belt + 3:1 spur stage, **6:1 total** | [FCStd](./FreeCAD/Ver.3/A/Ver3_A.FCStd) · [STEP](./FreeCAD/Ver.3/A/Ver3_A.step) · [STL](./STL/Ver.3/A) · [BOM](./docs/ver3/BOM_A.csv) |
| **B — Small rotor, high reduction** | 90 × 180 mm | Three 4:1 spur stages, **64:1**; slower motion and more starting losses | [FCStd](./FreeCAD/Ver.3/B/Ver3_B.FCStd) · [STEP](./FreeCAD/Ver.3/B/Ver3_B.step) · [STL](./STL/Ver.3/B) · [BOM](./docs/ver3/BOM_B.csv) |
| **C — Intermediate, generated frame** | 180 × 180 mm | Two spur stages, **16:1**, constrained parametric rib generation | [FCStd](./FreeCAD/Ver.3/C/Ver3_C.FCStd) · [STEP](./FreeCAD/Ver.3/C/Ver3_C.step) · [STL](./STL/Ver.3/C) · [BOM](./docs/ver3/BOM_C.csv) |

Nominal all-solid CAD plus catalog/assumed hardware masses are approximately **4.06 / 4.66 / 3.42 kg**—not measured or slicer masses. C is the suggested first **assembly and joint-resistance test**, not a validated wind-walking recommendation.

Contact-derived walking preview

**Walking:** [A, 1×](./docs/ver3/media/walking_A.mp4) · [B, 8×](./docs/ver3/media/walking_B.mp4) · [C, 2×](./docs/ver3/media/walking_C.mp4)  
**Mechanism and assembly:** [Operation](./docs/ver3/media/operation.mp4) · [Exploded illustration](./docs/ver3/media/exploded.mp4) · [Native Blender](./Blender/Ver.3/ver3_ABC.blend)

The walking scenes use the actual linkage lengths, phases and ratios. Body motion is derived from foot-contact geometry and material-point anchors, not an arbitrary sliding translation. At the common **prescribed rotor input of 120 rpm**, three crank cycles take A 9 s, B 96 s and C 24 s; the playback multipliers are explicit. This is **kinematic visualization with contact approximations**, not wind/contact dynamics.

The strict 3 mm contact target remains **unmet**: maximum material-anchor drift **within one uninterrupted ≥2%-load episode**, including clip-entry partial episodes, is approximately **9.55 / 10.30 / 8.88 mm**. These are not three-cycle accumulated slip distances. Small positive support margins are not practical stability guarantees. See the [results and definitions](./docs/ver3/comparison.json) for the separate all-near-foot audit, interval-specific drift/path metrics, floor checks and CG/wind sensitivity.

Under the common nominal friction assumptions, peak required input torques are about **0.0478 / 0.00690 / 0.0155 Nm**. Even the optimistic assumed 8 m/s, torque-coefficient-0.20 input is insufficient for B's nominal startup case. No design is promised to start at a particular wind speed or every rotor angle.

[Design, evidence and regeneration](./docs/ver3/DESIGN_en.md) · [Assembly and bench checklist](./docs/ver3/ASSEMBLY_en.md) · [Actual CAD sections](./docs/ver3/drawings) · [Comparison CSV](./docs/ver3/comparison.csv) · [Independent review](./docs/ver3/REVIEW_en.md)

“Generative Design” here means an **executed, reproducible parametric design-space search**, not Autodesk Generative Design, CFD, continuum FEA or topology optimization. Print Ver.3 STLs at **100% in millimetres**; do not reapply the historical 150% scaling. These are new concepts, not reconstructed native Ver.2 CAD or guaranteed drop-in replacements.

**Project showcase:** [Explore current Ver.3.1 and the Ver.1/2/3.0 history in English](https://ktanino10.github.io/TeoJansen_Rhinoceros/en/) — each page links to its Japanese counterpart. Current and archived geometry, media and downloads are explicitly separated; physical performance remains unverified.

**Photo-led production history:** [Ver.1 design, printing, finishing and assembly](https://ktanino10.github.io/TeoJansen_Rhinoceros/en/production.html#ver1) / [Ver.2 revisions, completed-model views and tests](https://ktanino10.github.io/TeoJansen_Rhinoceros/en/production.html#ver2). These pages organize this README's records, with six authentic completed-model views per version. They do not reconstruct an undocumented Ver.2 manufacturing log or native CAD.

**Ver.3.0 archive:** [Initial change/evidence matrix, videos and old downloads](https://ktanino10.github.io/TeoJansen_Rhinoceros/en/comparison.html) / [Archived A/B/C 360° and assembly](https://ktanino10.github.io/TeoJansen_Rhinoceros/en/viewer.html). Both languages retain the original CAD meshes, instance IDs and first-cut limitations, including the unmet contact target and B input-torque shortfall.

**Ver.3.1 current design (engineering r7/floor2):** [Comparison, 360°, 12 stages and current downloads](https://ktanino10.github.io/TeoJansen_Rhinoceros/en/r7.html). All 2,285 instances are retained; the JPY24,000 material reference excludes tools, shipping and unresolved taxes. Seven representative slicing inspections do not qualify physical printing. No walking prototype is qualified. Earlier first-cut material and internal research remain history.

**Continuous walking:** [Interactive walking and language-specific videos](https://ktanino10.github.io/TeoJansen_Rhinoceros/en/walking.html) use a separate prescribed-120-rpm kinematic/quasi-static display model, with explicit contact realignment, airborne-rocker and spring assumptions. Videos use 16× time compression. They do not demonstrate physical wind-driven self-starting or a measured 30 cm walk; canonical null rocker angles remain unchanged.

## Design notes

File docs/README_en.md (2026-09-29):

# Documents in English

[日本語](README_ja.md) | [English](README_en.md)

Full English counterparts of the major public documents. Frozen Japanese engineering originals remain unchanged; each translation identifies its source SHA256. The language switch on every website page retains the page, query and anchor.

[English website](https://ktanino10.github.io/TeoJansen_Rhinoceros/en/) · [How to use / resource legend](USER_GUIDE_en.md) · [Source and coverage manifest](translation-manifest.json)

**Current: Ver.3.1** (engineering `v3-integrated-walkers-r7-16-floor2`). **Archive: Ver.3.0** (first-cut concepts). Original engineering titles, IDs and hashes are retained; r2/r3/r4/r6 are internal study/subassembly revisions, not public product versions.

[Ver.3.1 comparison / 360° / assembly](https://ktanino10.github.io/TeoJansen_Rhinoceros/en/r7.html) · [Current native CAD / STEP / STL / BOM](https://ktanino10.github.io/TeoJansen_Rhinoceros/en/index.html#downloads) · [Current walking display / videos](https://ktanino10.github.io/TeoJansen_Rhinoceros/en/walking.html)

## Ver.3.1 — Current design and source records

| Document | 日本語 | English |
|---|---|---|
| Ver.3, 3 integrated designs: whole-machine geometry and conditional judgments | [日本語](ver3/integrated_r7/README_ja.md) | [English](ver3/integrated_r7/README_en.md) |
| Common assembly — Whole-machine r7 | [日本語](ver3/integrated_r7/ASSEMBLY_ja.md) | [English](ver3/integrated_r7/ASSEMBLY_en.md) |
| r7-15 independent integration review and bounded correction | [日本語](ver3/integrated_r7/REVIEW_ja.md) | [English](ver3/integrated_r7/REVIEW_en.md) |
| r7-16-floor2: bounded floor, gear and commercial-fastener corrections | [日本語](ver3/integrated_r7/FLOOR_CORRECTION_ja.md) | [English](ver3/integrated_r7/FLOOR_CORRECTION_en.md) |
| Display frames from the existing contact model | [日本語](ver3/integrated_r7/CONTACT_FRAMES_ja.md) | [English](ver3/integrated_r7/CONTACT_FRAMES_en.md) |
| r7: actual toolpath inspection of 5 representative parts | [日本語](ver3/integrated_r7/SLICING_ja.md) | [English](ver3/integrated_r7/SLICING_en.md) |
| A: whole-machine design assessment | [日本語](ver3/integrated_r7/A/README_ja.md) | [English](ver3/integrated_r7/A/README_en.md) |
| B: whole-machine design assessment | [日本語](ver3/integrated_r7/B/README_ja.md) | [English](ver3/integrated_r7/B/README_en.md) |
| C: whole-machine design assessment | [日本語](ver3/integrated_r7/C/README_ja.md) | [English](ver3/integrated_r7/C/README_en.md) |
| C shifted gear pair: 2 additional slices | [日本語](ver3/integrated_r7/C/SLICING_ja.md) | [English](ver3/integrated_r7/C/SLICING_en.md) |
| Floor-corrected r7: continuous-walking display model v1 | [日本語](ver3/r7_walking_v1/MODEL_ja.md) | [English](ver3/r7_walking_v1/MODEL_en.md) |

## Ver.3.0 — Initial concepts (archive)

| Document | 日本語 | English |
|---|---|---|
| Ver.3 — Design, calculation and generative-design notes | [日本語](ver3/DESIGN_ja.md) | [English](ver3/DESIGN_en.md) |
| Ver.3 — Assembly, installation paths and bench checks | [日本語](ver3/ASSEMBLY_ja.md) | [English](ver3/ASSEMBLY_en.md) |
| Ver.3 independent review and corrections | [日本語](ver3/REVIEW_ja.md) | [English](ver3/REVIEW_en.md) |

## Internal studies and subassemblies (separate conditions)

| Document | 日本語 | English |
|---|---|---|
| Bounded redesign using a common commercial-dryer reference | [日本語](ver3/commercial_basis_r3/DESIGN_GATE_ja.md) | [English](ver3/commercial_basis_r3/DESIGN_GATE_en.md) |
| Optional noninvasive V2 checks — No instrument purchase | [日本語](ver3/commercial_basis_r3/V2_CHECK_ja.md) | [English](ver3/commercial_basis_r3/V2_CHECK_en.md) |
| Common input cartridge — Actual CAD of holder and test flange | [日本語](ver3/common_input_r4/README_ja.md) | [English](ver3/common_input_r4/README_en.md) |
| Common input cartridge assembly and removal | [日本語](ver3/common_input_r4/ASSEMBLY_ja.md) | [English](ver3/common_input_r4/ASSEMBLY_en.md) |

## Shared and original-language resources

The seven BOMs already use English/neutral fields and are shared byte-for-byte: part IDs, quantities, SKUs, prices and URLs are unchanged. CAD/STEP/STL/GLB and numerical sources are shared, not remodeled. Source JSON annotations may be Japanese; paired prose supplies the English explanation. Original Ver.1 PDFs are **Original drawing (Japanese)**, not translated English drawings. Photos are unchanged and external videos retain their actual original language.

## Archival Japanese originals

The earlier feasibility/wind-module studies and detailed archived reviewer logs below remain Japanese source records. They are explicitly labeled when cited, not substituted for English major-document downloads.
- [ver3/feasibility_r2/GATE_ja.md — Japanese original](ver3/feasibility_r2/GATE_ja.md)
- [ver3/feasibility_r2/MEASUREMENT_ja.md — Japanese original](ver3/feasibility_r2/MEASUREMENT_ja.md)
- [ver3/integrated_r7/review/FOLLOWUP_R7-I1_ja.md — Japanese original](ver3/integrated_r7/review/FOLLOWUP_R7-I1_ja.md)
- [ver3/integrated_r7/review/INITIAL_REVIEW_ja.md — Japanese original](ver3/integrated_r7/review/INITIAL_REVIEW_ja.md)
- [ver3/wind_module_r6/ASSEMBLY_ja.md — Japanese original](ver3/wind_module_r6/ASSEMBLY_ja.md)
- [ver3/wind_module_r6/README_ja.md — Japanese original](ver3/wind_module_r6/README_ja.md)
- [ver3/wind_module_r6/REVIEW_ja.md — Japanese original](ver3/wind_module_r6/REVIEW_ja.md)

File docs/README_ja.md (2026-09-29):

# 日本語の資料

[日本語](README_ja.md) | [English](README_en.md)

公開ページから参照する主要資料の日本語・英語対応表です。固定された日本語の機械資料は変更せず、英語版に原本SHA256を記録しています。サイトの言語切替は同じページ・クエリ・アンカーを保持します。

[日本語サイト](https://ktanino10.github.io/TeoJansen_Rhinoceros/) · [使い方・資料の凡例](USER_GUIDE_ja.md) · [出典・対応範囲manifest](translation-manifest.json)

**現行：Ver.3.1**（内部設計ID `v3-integrated-walkers-r7-16-floor2`）。**履歴：Ver.3.0**（第一カットの初期比較案）。原資料の題名・ID・ハッシュは保持しています。r2/r3/r4/r6は内部研究・部分設計の改訂で、作品の公開版番号ではありません。

[Ver.3.1 比較・360°・組立](https://ktanino10.github.io/TeoJansen_Rhinoceros/r7.html) · [現行CAD・STEP・STL・BOM](https://ktanino10.github.io/TeoJansen_Rhinoceros/index.html#downloads) · [現行の連続歩行表示・動画](https://ktanino10.github.io/TeoJansen_Rhinoceros/walking.html)

## Ver.3.1 — 現行設計と出典資料

| 資料 | 日本語 | English |
|---|---|---|
| Ver.3 統合3案：全体実体と条件付き判断 | [日本語](ver3/integrated_r7/README_ja.md) | [English](ver3/integrated_r7/README_en.md) |
| 共通組立手順 — 全機r7 | [日本語](ver3/integrated_r7/ASSEMBLY_ja.md) | [English](ver3/integrated_r7/ASSEMBLY_en.md) |
| r7-15 独立統合レビューと限定是正 | [日本語](ver3/integrated_r7/REVIEW_ja.md) | [English](ver3/integrated_r7/REVIEW_en.md) |
| r7-16-floor2：床干渉・歯車・市販締結の限定是正 | [日本語](ver3/integrated_r7/FLOOR_CORRECTION_ja.md) | [English](ver3/integrated_r7/FLOOR_CORRECTION_en.md) |
| 既存接地モデルの描画用フレーム | [日本語](ver3/integrated_r7/CONTACT_FRAMES_ja.md) | [English](ver3/integrated_r7/CONTACT_FRAMES_en.md) |
| r7 代表5点の実ツールパス点検 | [日本語](ver3/integrated_r7/SLICING_ja.md) | [English](ver3/integrated_r7/SLICING_en.md) |
| A：全体モデルの判断資料 | [日本語](ver3/integrated_r7/A/README_ja.md) | [English](ver3/integrated_r7/A/README_en.md) |
| B：全体モデルの判断資料 | [日本語](ver3/integrated_r7/B/README_ja.md) | [English](ver3/integrated_r7/B/README_en.md) |
| C：全体モデルの判断資料 | [日本語](ver3/integrated_r7/C/README_ja.md) | [English](ver3/integrated_r7/C/README_en.md) |
| C転位歯車対の追加2点スライス | [日本語](ver3/integrated_r7/C/SLICING_ja.md) | [English](ver3/integrated_r7/C/SLICING_en.md) |
| r7床是正版・連続歩行の表示モデル v1 | [日本語](ver3/r7_walking_v1/MODEL_ja.md) | [English](ver3/r7_walking_v1/MODEL_en.md) |

## Ver.3.0 — 初期比較案（履歴）

| 資料 | 日本語 | English |
|---|---|---|
| Ver.3 — 設計・計算・生成設計ノート | [日本語](ver3/DESIGN_ja.md) | [English](ver3/DESIGN_en.md) |
| Ver.3 — 組立・装着経路・ベンチ確認 | [日本語](ver3/ASSEMBLY_ja.md) | [English](ver3/ASSEMBLY_en.md) |
| Ver.3 独立レビューと是正記録 | [日本語](ver3/REVIEW_ja.md) | [English](ver3/REVIEW_en.md) |

## 内部研究・部分設計（別条件）

| 資料 | 日本語 | English |
|---|---|---|
| 共通市販ドライヤー基準による限定再設計 | [日本語](ver3/commercial_basis_r3/DESIGN_GATE_ja.md) | [English](ver3/commercial_basis_r3/DESIGN_GATE_en.md) |
| 任意のV2非侵襲チェック — 測定器は購入しない | [日本語](ver3/commercial_basis_r3/V2_CHECK_ja.md) | [English](ver3/commercial_basis_r3/V2_CHECK_en.md) |
| 共通入力カートリッジ — ホルダー・試験フランジの実CAD | [日本語](ver3/common_input_r4/README_ja.md) | [English](ver3/common_input_r4/README_en.md) |
| 共通入力カートリッジの組立・脱着 | [日本語](ver3/common_input_r4/ASSEMBLY_ja.md) | [English](ver3/common_input_r4/ASSEMBLY_en.md) |

## 共通データと原本の言語

7つのBOMは英語・共通の項目で、バイト単位で同じ原本を参照します。部品ID・数量・SKU・価格・URLは不変です。CAD・STEP・STL・GLB・数値原本は共通で、再設計していません。JSONの原注記には日本語が含まれる場合があり、解説は対訳資料を使用します。Ver.1のPDFは**原図（日本語）**で、英訳図面とは表示しません。原写真と外部動画の言語は変更しません。

## 日本語のまま保持する補助的な履歴

以前の成立性・風車モジュールの研究と、保存した詳細レビュー原本は以下の日本語資料です。英語の主要資料ダウンロードの代わりにはせず、引用時に原本の言語を明示します。
- [ver3/feasibility_r2/GATE_ja.md — 日本語原本](ver3/feasibility_r2/GATE_ja.md)
- [ver3/feasibility_r2/MEASUREMENT_ja.md — 日本語原本](ver3/feasibility_r2/MEASUREMENT_ja.md)
- [ver3/integrated_r7/review/FOLLOWUP_R7-I1_ja.md — 日本語原本](ver3/integrated_r7/review/FOLLOWUP_R7-I1_ja.md)
- [ver3/integrated_r7/review/INITIAL_REVIEW_ja.md — 日本語原本](ver3/integrated_r7/review/INITIAL_REVIEW_ja.md)
- [ver3/wind_module_r6/ASSEMBLY_ja.md — 日本語原本](ver3/wind_module_r6/ASSEMBLY_ja.md)
- [ver3/wind_module_r6/README_ja.md — 日本語原本](ver3/wind_module_r6/README_ja.md)
- [ver3/wind_module_r6/REVIEW_ja.md — 日本語原本](ver3/wind_module_r6/REVIEW_ja.md)

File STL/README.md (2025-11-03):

# STL Files for 3D Printing

This directory contains STL files for 3D printing the components of the Theo Jansen Rhinoceros kinetic sculpture.

## Files

Place your `.stl` files here for each component that needs to be 3D printed.

## Printing Guidelines

- Recommended layer height: 0.2mm
- Infill: 20-30% for most parts
- Supports: May be needed for some parts
- Material: PLA or PETG recommended

## Assembly

Refer to the main documentation for assembly instructions and how these parts fit together.

## Notes

- STL files are provided for educational and non-commercial purposes
- Test print one component first to verify scale and fit

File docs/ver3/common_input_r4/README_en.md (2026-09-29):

# Common input cartridge — Actual CAD of holder and test flange

[日本語 (original)](README_ja.md) | **English** | [Document languages](../../README_en.md)

> Presentation-only translation of the unchanged Japanese source. Source SHA256: `85509d69ae32ea690813f2ff591a5b669c379f4e1ef80a25ecb1a6807ac23db8`. Numbers, part IDs, equations, code and qualification limits are retained; this is not a new engineering revision.

**`v3-common-input-r4-01`. Actual CAD of 1 input assembly, not demonstrated low resistance, manufacturing release or completion of three walkers.**

The preceding [common-cold-air study](../commercial_basis_r3/DESIGN_GATE_en.md) is not overwritten. Without expanding rotor/gear/leg searches, this revision is limited to 1 set of a commercial 120 mm D-shaft, 2 bearings, metal D-hub and axial retention. **No shaft cutting, drilling or end tapping is needed.**

Input cartridge from actual CAD

## Files

| Contents | Canonical source |
|---|---|
| Native FreeCAD | [CommonInputR4.FCStd](../../../FreeCAD/Ver.3/common_input_r4/CommonInputR4.FCStd) |
| STEP | [CommonInputR4.step](../../../FreeCAD/Ver.3/common_input_r4/CommonInputR4.step) |
| Printable STL | [Carrier](../../../STL/Ver.3/common_input_r4/P_CARRIER.stl), [retainers ×2](../../../STL/Ver.3/common_input_r4/P_CAP.stl), [test flange](../../../STL/Ver.3/common_input_r4/P_FLANGE.stl), [fit coupon](../../../STL/Ver.3/common_input_r4/Q_BEARING_FIT.stl) |
| Assembly and BOM | [Instructions](ASSEMBLY_en.md), [BOM.csv](BOM.csv), [canonical placements and operation set](assembly.json) |
| Dimensions and generation | [input_cartridge.json](../../../scripts/ver3/input_cartridge.json), [CAD generator](../../../scripts/ver3/build_input_cartridge.py) |
| Contacts and paths | [assembly_access.json](assembly_access.json), [tolerance stack](tolerance_stack.json) |
| Mass, cost and numerical results | [CAD checks](cad_validation.json), [procurement](procurement.json), [shaft beam model](shaft_mechanics.json), [STL checks](stl_validation.json) |
| Revision, sources and hashes | [manifest.json](manifest.json) |

FreeCAD contains 36 named Part features with IDs, specifications and mass bases. JSON/scripts govern parameters; this is not a Sketcher history driven by arbitrary display-property edits. Native/STEP agree at 44 solids. Purchased internals are **new dimension models**, not copied/distributed manufacturer proprietary shapes, B-rep, drawings or meshes.

## What became concrete

| Item | Result in this revision | Still unverified |
|---|---|---|
| Carrier | Integral supports, cap seats, bearing-flange grooves and 4 mounting holes | Actual shrinkage, alignment and layer-direction strength |
| Location | **2 collars and 2 spacers straddle the left 1 bearing**. Total inner-ring-stack play 0.20 mm | Actual bearing internal clearance and end play after tightening |
| Floating support | Right outer-ring flange axial travel 2.00 mm total, nominal ±1.00 mm | Actual free movement including fit and support deformation |
| Torque transmission | 6 mm D-shaft → manufacturer-specified metal D-hub → 4 M4 bolts on a 16 mm square → test flange | Tightening, physical torque capacity and fatigue |
| Removal / installation | Checked sequence: both caps first, preassembled hub/flange, shaft insertion from left | Finger access and all tool/tolerance conditions |
| Starting resistance | Geometry excludes unwanted nominal contacts; resistance remains an independent sensitivity input | **Actual starting/running resistance is unpublished and unmeasured** |

## Locating/floating sides and overtightening preload

Actual-CAD section

X is axial, Y lateral, Z vertical. Shaft center Z=30 mm; support centers X=16.5/96.5 mm, 80 mm apart.

Left locating side provides 1.30 mm pocket depth for a 1.00 mm outer-ring flange. **The 3 mm cap seats on carrier side lands, not against the bearing face.** Commercial steel spacers, about 8 mm OD and 4 mm long, sit before/after the inner ring to clear the collar's 9 mm boss from thin caps. Canonical CAD uses manufacturer-reference 6.05 mm ID/7.95 mm OD spacers.

Instead of the previous candidate's 1 collar at each shaft end, **both 2 collars straddle the locating side**. No added right-bearing collar clamps the whole span through multiple inner rings.

| Nominal dimensions and acceptance scenarios | Value |
|---|---:|
| Locating outer-ring axial play | 0.30mm |
| Total collar play around locating inner ring + 2 spacers | 0.20mm |
| Total floating outer-flange travel | 2.00mm |
| Remaining locating outer-ring gap at acceptance extremes | Minimum 0.10 mm |
| Remaining one-sided float allowance at acceptance extremes | Minimum 0.05 mm |

Pocket error ±0.10 mm, flange-thickness error ±0.05 mm and cap-compression allowance 0.05 mm are **design acceptance conditions to check before adoption**, not guaranteed delivery tolerances. Recalculate if actual parts/material/tightening do not meet them. Tightening until caps sink, forcing collars to eliminate play or pulling tight bearings in with bolts is not assumed.

Nominal minimum cylindrical support length at the floating end is about 2 mm. The flange also guides radially, but radial play, tilt and retaining stiffness are not guaranteed. Check coupons and free physical movement; reject tilt-induced binding. Rotor load, gear mesh and machine mounting belong to the next integration stage.

## D-hub: neither “tiny overlap means incompatible” nor “enlarge it to pass”

Manufacturer [1309-0016-1006](https://www.gobilda.com/1309-series-sonic-hub-6mm-d-bore/) explicitly specifies a 6 mm D-shaft, 2 clamp screws and release during disassembly. This **manufacturer-specified combination** supports design compatibility.

However, manufacturer STEP puts the hub D-flat about 2.48 mm from center and shaft flat about 2.50 mm, producing about 0.669 mm³ nominal overlap. Open/clamped reference state, numerical tolerance and clamping displacement are undocumented. **No hub enlargement or fictitious shaft shaving removes it.** The exception remains “manufacturer-specified clamp interface, state unverified,” separate from physical insertion, tightening and torque checks.

The hub's 4 mounting holes form a square at center ±8 mm; pilot is 14×2 mm. A 4 mm test flange, 1 mm washers and M4×12 give nominal engagement 7 mm and 1 mm to the hub rear. Threadless CAD contact volumes are not interference-free clearance fits.

The product page lists hub mass 14 g, while an older linked sheet says 9.6 g. Whether this reflects bolts/body-only or revision differences is unresolved. **The earlier 4-item 59 g subtotal remains a purchased-assembly reference using 14 g, not conveniently reduced to 9.6 g.**

## Small BOM, mass and cost

All parts serve this one input cartridge, not an instruction to duplicate imports across every leg/shaft. Purchased hub/collar assemblies include clamp screws; they are not counted twice.

| Part number | Required quantity | Purchase unit | Displayed USD unit price | Evidence |
|---|---:|---:|---:|---|
| 2101-0006-0120, 6 mm D-shaft, 120 mm long | 1 | 1 shaft(s) | 4.69 | [Manufacturer](https://www.gobilda.com/2101-series-stainless-steel-d-shaft-6mm-diameter-120mm-length/) |
| 1611-0514-0006, flanged bearing | 2 | 2 piece(s) | 3.99 | [Manufacturer](https://www.gobilda.com/1611-series-flanged-ball-bearing-6mm-id-x-14mm-od-5mm-thickness-2-pack/) |
| 2910-0919-0006, clamp collar | 2 | 1-pack ×2 | 4.49/piece | [Manufacturer](https://www.gobilda.com/2910-series-aluminum-clamping-collar-6mm-id-x-19mm-od-9mm-length/) |
| 1309-0016-1006, metal D-hub | 1 | 1 piece(s) | 7.99 | [Manufacturer](https://www.gobilda.com/1309-series-sonic-hub-6mm-d-bore/) |
| 1521-0008-0040, 4 mm steel spacer | 2 | 4 piece(s) | 2.49 | [Manufacturer](https://www.gobilda.com/1521-series-6mm-id-spacer-8mm-od-4mm-length-4-pack/) |
| 2800-0004-0012、M4×12 | 4 | 25 shaft(s) | 3.59 | [Manufacturer](https://www.gobilda.com/m4-x-0-7mm-zinc-plated-socket-head-screw-12mm-length/) |
| 2800-0004-0020、M4×20 | 4 | 25 shaft(s) | 3.99 | [Manufacturer](https://www.gobilda.com/m4-x-0-7mm-zinc-plated-socket-head-screw-20mm-length-25-pack/) |
| 2801-0004-0008, 4×8×1 mm washer | 12 | 25 washer(s) | 1.99 | [Manufacturer](https://www.gobilda.com/2801-series-zinc-plated-steel-washer-4mm-id-x-8mm-od/) |
| 2812-0004-0007, M4 locknut | 4 | 25 piece(s) | 2.99 | [Manufacturer](https://www.gobilda.com/m4-x-0-7mm-nylock-nut/) |
| Printed: carrier / retainers / flange | 1／2／1 | As listed in STL quantities | Material price assumed | [BOM](BOM.csv) |

**Minimum purchase lots including surplus, not just installed quantities: $40.70.** At assumed JPY 140/160/180 per USD: JPY 5,698/6,512/7,326. Japan shipping, import taxes and exchange/payment fees remain separate and unresolved. Prices/options displayed on month 9, day 27 do not reserve stock or guarantee arrival.

| Mass | Evidence | Value |
|---|---|---:|
| Earlier subtotal of 4 items only | Nominal purchase-page values | **59.00g** |
| All purchased parts | Above plus spacers and all fasteners | **85.28g** |
| 4 printed solids | Actual CAD solid volume × assumed PETG density 1.27 g/cm³ | **39.70g** |
| Cartridge total | Sum of the above 2 entries | **124.98g** |
| Measured / sliced mass | Not performed | **UNKNOWN** |

Fit coupons have assembly quantity 0 and are excluded from machine mass. At assumed filament JPY 2,000–4,000/kg and 1.2× support allowance, body material costs about JPY 95–191; this is not actual sliced consumption or purchase of 1 spool. Initial cost separately includes 1 coupon(s), about 13 g, distinguished from body-only in `procurement.json`'s `firstPrintIncludingCouponAndWasteCostJpy`. Failed prints/reprints are unresolved. **This small BOM does not establish a complete-walker budget of 2 × 10,000 JPY.** The 4 stand/machine mounting screws are excluded because mating thickness is unset; this does not permit unmounted operation.

## Checks performed

Actual manufacturer STEP was read privately and compared separately with new public dimension models. Vendor geometry is not distributed.

- Checked 630 static pairs and 7,560 moving/fixed combinations at 24 poses spaced 15°. No overlap outside threaded and designated D-clamp interfaces.
- Sampled rotating/printed minimum clearance about 1.080 mm. Also checked all rotating parts at X=−0.60/0/+0.15 mm and 30° increments.
- Left outer-ring travel −0.30–0 mm and right travel ±1 mm gave carrier/retainer overlap 0.
- Front/rear 4 mm spacers each contact actual manufacturer inner-ring faces over about 13.91 mm².
- Recorded bearing-then-cap order, leftward shaft extraction, upward hub/flange extraction after shaft removal and upper clamp-key access at selected stop angles.
- Native reload: 36 objects, 44 solids; matching STEP volumes/placements. 4 STL types are closed single solids within 230 mm bounds.

These check stated samples/tool envelopes, **not every continuous path, finger, tool or physical tolerance condition**. Free passage through the 6 mm bearing bore and D-clamp requires manufacturer specifications and physical checks.

## Do not confuse demand, resistance and margin

A simply supported shaft-only screen with 80 mm support spacing and 2 N at X=67 mm gives maximum deflection about 0.00183 mm and bending stress 2.11 MPa. At 12 Nmm torsion, twist is bounded around 0.000102–0.000144 rad. **D-section torsion constant is not replaced by polar second moment.** Loads/E/G are rounded comparative assumptions near R3 inputs, not actual/allowable test loads or material certificates.

Holder, printed-seat and fastening deformation are excluded. Manufacturer starting/running torque values were not found; 0.2/0.6/2.0 Nmm for 2 bearings remain **sensitivity inputs**. Selecting parts or avoiding CAD rubbing does not establish that physical resistance stays below them.

Net fluid-torque proxy, actual-part resistance and optional downstream 2× margin/supply derating 0.5 are separate. Defining cartridge geometry does not turn uncalibrated fluid values into guarantees.

## Regeneration

Uses existing FreeCAD 1.1.3 bundled Python and NumPy/SciPy/trimesh. Manufacturer parts are individually downloaded into private folders outside the repository as `bearing.step / collar.step / shaft.step / hub.step / spacer.step`. Public downloads are not redistributed.

```sh
/Applications/FreeCAD.app/Contents/Resources/bin/python \
  scripts/ver3/build_input_cartridge.py \
  --freecad-lib /Applications/FreeCAD.app/Contents/Resources/lib \
  --vendor-dir /path/to/private-reference
python3 -m unittest discover -s scripts/ver3 -p 'test_input_cartridge.py' -v
python3 scripts/ver3/cartridge_report.py
python3 scripts/ver3/cartridge_report.py --verify
```

These commands generate/check data; they do not operate printers, dryers or the user's live CAD scene. Native files contain timestamps, so byte differences are not automatically geometry differences; compare shape, placement, volume and input hashes.

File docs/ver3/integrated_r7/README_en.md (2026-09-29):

# Ver.3, 3 integrated designs: whole-machine geometry and conditional judgments

[日本語 (original)](README_ja.md) | **English** | [Document languages](../../README_en.md)

> Presentation-only translation of the unchanged Japanese source. Source SHA256: `cd8bf579f31b2316acab4d63d9c7b04016f498f3dcd0c633e6b3f991be0511b8`. Numbers, part IDs, equations, code and qualification limits are retained; this is not a new engineering revision.

**The primary requirement of 3 demonstrably working machines is unfinished.**
Old r3/r4/r6 and the public first cut are unchanged. This folder integrates new whole-machine CAD, complete BOMs, contact/drive calculations and assembly paths in one revision.
manufacturingRelease=false; qualified walkers=0. No purchasing, printing or dryer operation occurred. Publishing design documents in the existing repository/Pages is distinct from physical qualification.

[Independent-review history](REVIEW_en.md) covers only old r7-15 and R7-I1. Current [floor correction](FLOOR_CORRECTION_en.md) changes C's stage distribution, all PET lower edges and rocker-pin regions, updating mass, loads and all-body floor checks coherently. This is not new independent endorsement.

Current indicative design budget: **about JPY 24,000 in materials for 1 machine** (user approval 2026-09-28 JST). Shipping, unresolved taxes and unowned tools such as DN-03 at about JPY 396 are separate. Individual first purchases and shared lots are distinct; no purchases were made.

|Design|Diameter / reduction|Nominal g|Individual first purchase, JPY|Raw proxy / nominal demand, mN·m|Slip work, Nmm/cycle|30 cm time at assumed 120 RPM, min|
|---|---:|---:|---:|---:|---:|---:|
|[A](A/README_en.md)|220/144|1065.39|23,305|1.6166/1.4344|47.13|3.90|
|[B](B/README_en.md)|160/512|1101.37|23,735|1.1566/0.9422|50.05|13.83|
|[C](C/README_en.md)|200/156|1031.43|23,154|1.4629/1.3463|44.34|4.22|

## Same-definition comparison with old A

|Item|Stored old A|Final A|Change|
|---|---:|---:|---:|
|Nominal mass, g|977.709|1065.388|+8.97%|
|Input demand with final equations at 0.5° steps, mN·m|2.5798|1.4344|-44.40%|
|Nonnegative floor-slip work, Nmm/cycle|24.1646|47.1326|+95.05%|

Old 2.84621 mN·m is a historical result from the old model, distinct from the same-equation recalculated baseline. Equation corrections are not mechanical improvements. Old A lacked the full guards/initial accessories, so price and completeness are not equivalent.
Finite static checks, 216 poses and 162 support cases verify their specified subjects/assumptions. Input 120 RPM is not a predicted achieved speed.

## Actual changes in this revision
Uses smooth commercial 4 mm metal sleeves and M2 axial fastening, not threads as sliding surfaces.
PC pitch changes 25.545→26.5 mm, retaining circle-intersection closure margin with pitch error and both-end pin clearances. Coordinate-order branch switching was replaced by equations preserving the same assembly branch.
42-tooth synchronization gears and 84 mm shaft pitch provide actual clearance to downstream gears/guards, not wider feet or added ballast.
Includes real 16-sided prism sections, keyed split frames, rotor guard split into front basket/rear cap, and PET side guards whose clamp load bypasses the sheet through steel washers.
2 commercial collars are clocked without changing position to reduce nominal gravitational imbalance. Physical balance is unmeasured.

Floor correction redistributes C to 13×12; pair 1 uses m0.9, 20°, profile shifts +0.35/−0.35; final gear m1, 144 teeth. PET lower edges, stepped seats, small M4 washers and noncontact bosses are revised. Commercial M2×12, nylon locknuts and actual DN-03 avoid precision cutting/thin tools. Foot positions, contact area, spring rate and 6 mm stroke are retained.

## Responses to V2 issues

|Observed issue|Concrete r7 response|Not yet qualified|
|---|---|---|
|Rotor/gears slipped relative to shafts and failed to transmit torque|Commercial metal 6D input hub; downstream 5 mm-AF positive engagement and smooth metal journals|Actual tightening, fit and endurance torque. Bearing seizure is not asserted as V2's cause|
|Weak self-starting|144/512/156:1 using actual-CAD mass and slip work, 4 mm journals and collar orientation reducing nominal imbalance|Uncalibrated aerodynamics, unmeasured friction and loaded rpm|
|Axial gear escape|Distinct locating/floating caps, shoulders, collars, sleeves and keyed frames|Physical tolerances, joint flexure and overtightening preload|
|Contact handoff and manufacturing error|PC26.5 mm, continuous branch, 84 mm synchronization pitch, actual springs/guides/rockers and 162 tolerance cases|Impact, wear and physical 30 cm walking. Slip is not eliminated|
|Insufficient integrated design covering procurement and assembly|Domestic downstream parts, all fasteners/guards/stand/coupons, split frames and machine-readable stages|No V2 native CAD exists; drop-in replacement is not established|

## Separate calculation corrections from mechanical improvements
First combine work from coaxial opposing legs/rotating fasteners, then count each actual gear pair's losses once. The old implementation assigning fictitious gear losses to 4 balanced bolts is not used.
Horizontal airflow force and yaw couple enter Coulomb ground reactions; actual-CAD centers of mass and contact poses are iteratively reconciled over all phases.
Numerical changes from equation/implementation corrections are distinct from lighter parts or better performance. The stored old 977.709 g baseline is recalculated with the same equations.
Gear-pair reaction upper bounds derived from real pitch radii/transmitted work are stored and added to input-shaft bending. This is not a same-load comparison with old gravity/wind-only beams, nor calibration of real bearing resistance or dynamic tooth friction.
Slip work remains nonnegative. 8 mm foot lift and 3 mm slip are older designer targets, not relabeled user requirements or erased failures.

## Essential remaining conditions
1. Actual aerodynamics/resistance: input-bearing resistance limits, print eccentricity and loaded rpm. Raw stationary proxy, design derating 0.5 and UNKNOWN measured lower bound are separate.
2. Fabrication/joints: 5 representative parts were actually sliced, but bottom support-film removal, tooth-bottom finishing, coupon fit, thin tips/layer strength and frame joints/retention/tools are unverified. Whole-machine printing or local beam fixity does not prove global stiffness.
3. Ground operation: finite-tolerance support cases and a physical 30 cm walk including slip, collisions and starting. Unperformed, so not counted as 3 qualified machines.

[Common assembly](ASSEMBLY_en.md) / [initial coupons and stand](common/accessories.json) / [shared lots for 3 machines](purchase_lots.json) / [integration contract](integration_contract.json) / [5 representative slices and remaining work](SLICING_en.md) / [canonical contact-frame scope](CONTACT_FRAMES_en.md)

## Reproduction environment
CAD used existing FreeCAD1.1.3 independent Python, numpy/scipy/Shapely/trimesh/Pillow/PyMuPDF. After approval, official OrcaSlicer2.4.2 was added in a dedicated area for representative slicing.
Python dependencies: `scripts/ver3/requirements_integrated_r7.txt`; canonical inputs: `scripts/ver3/walker_r7.json`. FreeCAD executable/library locations are explicit CLI arguments.
Final source/file hashes are in `integration_contract.json` and `manifest.json`. Generation does not publish to the network. Track deployment through main and normal Pages Actions, explicitly separate from the old first cut.

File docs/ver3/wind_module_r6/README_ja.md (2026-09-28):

# 裸16羽根＋入力軸の基準モジュール

**`v3-wind-module-r6-01`。径100mmの1モジュールを実CAD化しました。C歩行機の完成、自己始動・低抵抗の実証、製造リリースではありません。**

外形幅38mmと、根元板・端リングの間の**受風幅32mm**を区別します。軸高55mm、既製120mm・6mm D軸、同じ購入軸受・ハブ・カラーを使用します。r4の試験フランジを一体ローターへ、キャリアを高さ・補剛の派生品へ置き換えています。r4/r5は保存し、別候補群や全機動画は追加していません。

実CAD由来のモジュール

## 配布物

| 内容 | ファイル |
|---|---|
| FreeCAD／STEP | [WindModuleR6.FCStd](../../../FreeCAD/Ver.3/wind_module_r6/WindModuleR6.FCStd) / [STEP](../../../FreeCAD/Ver.3/wind_module_r6/WindModuleR6.step) |
| 印刷STL | [キャリア](../../../STL/Ver.3/wind_module_r6/P_CARRIER.stl)、[ローター](../../../STL/Ver.3/wind_module_r6/P_ROTOR.stl)、[押さえ×2](../../../STL/Ver.3/wind_module_r6/P_CAP.stl)、[数量0の試験片](../../../STL/Ver.3/wind_module_r6/Q_BEARING_FIT.stl) |
| 組立・部品 | [手順](ASSEMBLY_ja.md)、[BOM](BOM.csv)、[正規配置・段階集合](assembly.json)、[挿入／工具経路](assembly_access.json) |
| 形状・版 | [入力JSON](../../../scripts/ver3/wind_module.json)、[ネイティブ検査](cad_validation.json)、[STL検査](stl_validation.json)、[manifest](manifest.json) |
| 材料・構造 | [補剛比較](holder_sizing.json)、[実質量支持・差動・傾き](actual_mass_support.json)、[羽根／根元／端リング](rotor_strength_screens.json) |
| 風・回転力 | [風荷重](wind_loads.json)、[角度別生代理値](rotor_torque.csv)、[裸／下流接続条件](supply_required.json) |
| 費用 | [調達と材料費の条件表](procurement.json) |

ネイティブは36オブジェクト、44ソリッドです。購入部は自作したr4の寸法モデルを継承し、実メーカーB-repは私的な接触検査だけに使っています。メーカーCAD・図面画像を配布物へ入れていません。形状変更の正本はJSONとスクリプトで、Sketcherの対話履歴ではありません。

## 形状とトルク結合

根元板4mm、受風域32mm、端リング2mmで外形38mmです。16枚の羽根は曲がり角20°。中心線の外半径を49.2mmとし、**壁の厚さまで含めて**端リング・根元板の外径100mmに収めています。根元近くは厚さ2.4mmから1.6mmを経て薄部1.2mmへ、反対端も2.4mmへ変化する平面テーパーです。

ローターは根元・羽根・端リングが一つの閉じたソリッドです。端リングの40mm開口から根元の4本のM4へ工具を通す構成にして、回転後に取り付ける小ねじや接着を主トルク経路に使いません。根元の14.3mm・深さ2.15mmのパイロット座、16mm正方形の4穴は金属Dハブと同じ基準です。M4×12＋1mm座金により名目ねじかかり7mm、ハブ裏面まで1mmを残します。

メーカーの6mm D軸／ハブ対応指定を使いますが、参照CADのD平面2.48mm対軸2.50mmの微小交差は、開放／締結状態や数値公差が不明として別扱いです。拡大・切削したことにして合格化していません。現物の締付け・滑りトルクは未確認です。

軸受・軸・内輪の保持間隔はr4を継承。左固定側を2カラーと2鋼スペーサーで保持し、右外輪の名目±1mm浮動を残します。ローター外形の包絡は右固定部まで3mm、取付基準面まで5mm。軸方向受入位置の端も別に検査しています。**基台の相手材・固定ボルト・裏打ち剛性は未確定なので、運転可能とはしていません。**

## 補剛は絶対値から選定

同じ1N荷重で比較

r5の「同断面なら9.75倍」という比だけで部材を厚くしていません。同じ荷重・方向で、斜材なしと**6×6mmの斜材4本**だけを比較しました。主脚は8mm幅のままです。

| E=800MPaの同一条件 | 斜材なし | 採用斜材あり |
|---|---:|---:|
| 固定側Fx=1N：軸受中心の軸方向移動 | 0.08191mm | 0.02020mm |
| 同条件の部材軸力＋曲げ応力代理最大 | 0.282MPa | 0.096MPa |
| 同じ2N横荷重：左右軸受中心の差動横変位 | 0.00395mm | 0.00372mm |

計算は、実際の中心線・断面から作った3D Euler–Bernoulli梁フレーム近似です。リング・脚・斜材の中心線が実CAD材料内にあることを200点で照合しています。ソリッドFEMや積層樹脂の局所接着解析ではありません。軸受荷重は材料内のリング節点へ等価配分し、実際の玉・軌道の局所接触分布は解いていません。

E=800/1700/2600MPa、ポアソン比0.35、応力スクリーニング8MPaは設計仮定です。根元は剛い相手材で裏打ちされる境界条件で、実基台やボルトの柔らかさを解析済みとはしていません。梁計算器は既知の片持ち梁の各方向荷重・ねじり、座標回転、分割数、反力／モーメント平衡で照合します。

### 共通移動・差動・傾き・浮動余白を分離

実CAD質量の重力、風荷重の包絡、固定側Fx=−1/0/+1Nを重ねたケースでは、最大の**個別軸受中心の軸方向移動**は約0.02298mm。一方、浮動側に必要な長さの変化を表す**左右の差動＋軸の伸びの上界**は最大約0.02302mmです。共通モードの移動を差動の消費量へ加算していません。

FRAMEの材料リング面はX=17.85／95.50mm、軸受荷重点はX=16.50／96.50mmで一致しません。リング面の平均並進・平均回転を別々に保存し、**回転と軸方向オフセットの外積を加えて、実軸受荷重点へ変位を移送**します。この評価点で左右差・支持線傾斜を統一し、節点力／偏心モーメントの仕事と、荷重点の力／変位の仕事の一致を検査しています。これは[独立レビュー](REVIEW_ja.md)で指摘された初稿の評価点欠落を修正したものです。

| 診断 | 結果／扱い |
|---|---|
| ホルダー差動に割り当てる軸方向予算 | 0.025mm |
| 熱等の未モデル量へ残す予算 | 0.025mm |
| R4の元のホルダー／熱の合計予算 | 0.05mm |
| 軸弾性を含む差動の上界 | 約0.02302mm |
| 軸のたわみを加算した横方向相対ずれ上界 | 約0.00398mm |
| 支持の並進・回転と軸の曲げを合わせた相対傾き診断最大 | 約0.00115rad |
| 部分公差積層に残る片側浮動余白 | 最小約0.05198mm |
| **全組立の浮動余白の判定** | **UNKNOWN** |

0.05198mmは「実機でも十分に残る」と確認した値ではありません。ポケット・フランジ・カラー間隔・支持間隔の**設計受入範囲**に、今回計算した差動と熱予算を組み合わせた**部分計算**です。荷重時のキャップ曲げ・接合面の離れ／沈み、実軸受内部すきま、相手材・固定ボルト、実印刷・購入公差は未確定です。軸受メーカーの許容ミスアライメント値も未確認で、上の傾きを適合済みにしません。詳細は `actual_mass_support.json` の共通／差動・傾き・未算定項目を参照してください。

## 羽根・根元・端リング

羽根の曲げ近似

1枚の羽根に、採用したC_D=1.2とピーク動圧による幾何的な風荷重上界、自重、指定回転数の遠心力を同方向へ置くスクリーニングを行います。ピーク風を全面へ使う操作は**1枚の強度側の仮定**だけで、全ローターの供給電力へは使いません。

薄部1.2mmを全長32mmの片持ちとして扱い、根元2.4mmテーパーと端リングによる拘束の剛性効果を羽根側へ加点しません。根元は6mm幅の分担板ストリップ、端リングは隣接羽根間を単純支持とする別の近似です。実際のボルト／板接触や局所応力集中をソリッドで解いたものではありません。

E=800MPa・600rpmの**指定感度ケース**では、羽根先端＋根元回転の変位代理が最大約1.30mm、羽根曲げ応力代理は約1.24MPaです。無変形の隣接羽根間隔は約6.415mm。互いに逆向きに変形する上界を引く部分比較も保存します。根元板の軸方向曲げ、端リングの1N点荷重、フレーム差動・傾きによる軸方向クリアランス消費は別項目です。

**600rpmは予測回転数でも安全速度でもありません。** 空力は静止モデルであり、回転中の相対流れや回転速度を解いていません。積層接着・クリープ・疲労・実材料・実アンバランスは未検証です。ローターのCAD体積から求めた慣性モーメントは約`1.0894e-4 kg·m²`で、加速時には別途慣性トルクが必要です。

## 実CAD質量を入れた風荷重・回転力の条件表

風条件はr3と同じ、冷風・距離150mm・局所報告値6.4m/sをGaussianピークに置いた設計仮定、σ20mmです。メーカー機種の実測速度分布ではありません。今回の生代理値は、正規33分割中心線の半径49.2mmと受風幅32mmを使っています。壁厚テーパー・端リングの流れ・圧力回復・回転中性能はモデル化していません。

端板・購入回転部の包絡と固定部のCAD投影面へ同じ動圧を積分し、支持の追加荷重を見積もりました。回転部追加約0.00567N、固定部約0.00173Nの横力です。遮蔽を二重に数える可能性を含む**採用係数内の保守的荷重代理**であり、物理的な係数上限ではありません。これらを新たな供給トルクとして加点していません。

| 同一基準の診断 | 条件 | 結果 |
|---|---|---:|
| 生の静止ロータートルク代理・全角最小 | 未校正、減率なし | 約0.8127mN·m |
| 裸モジュールの入力軸受2個 | 名目抵抗仮定、理想バランス | 0.6000mN·m |
| 裸モジュールの生代理との差 | 同じ理想バランス条件 | 約+0.2127mN·m |
| 裸モジュールの減率0.5後との差 | 減率も未校正の設計入力 | 約−0.1937mN·m |
| 回転系全体の重心偏心0.1mm | 購入回転部も含む144.75g名目 | 生代理との差最小約+0.0723mN·m |
| 回転系全体の重心偏心0.5mm | 同じ抵抗仮定 | 生代理との差最小約−0.4923mN·m |
| Cの下流を仮に接続 | 下流入力軸換算 | 約0.7097mN·m |
| 同じC条件の総要求 | 入力軸受0.6を一回加算 | 約1.3097mN·m |
| C接続時・減率なし／余裕なしの位相対応差 | input角=25×crank角 | 最小約−0.4969mN·m |
| **実自己始動／実歩行** | 未測定 | **UNKNOWN** |

ローターの幾何学的重心は軸上ですが、実際の回転系バランスを保証しません。偏心感度は印刷ローターだけでなく購入ハブ・カラー・軸を含む回転系へ適用しています。

下流接続行は、未CADのr3脚／減速／重心目標・摩擦仮定を保持した条件計算です。旧入力＋ローターを一回取り除き、本モジュール213.26gを一回だけ入れ、C全機の名目質量仮定を約0.52487kgとして計算しています。新しい下流CADや噛合い、接地動力学を完成させたわけではありません。

下流の設計余裕2倍を使う場合も、**入力軸受後の下流要求にだけ倍率を掛け、入力軸受を一回戻す**定義です。総要求の単純2倍や、測った出力からの二重損失控除にはしません。裸0.8127と仮軸受0.6の大小から、脚・歯車を駆動できるとは結論していません。

## 質量・小BOM・費用

| 項目 | この版の名目値 |
|---|---:|
| 一体ローター：実CAD全ソリッド×仮定密度 | 81.31g |
| 補剛キャリア：同上 | 42.04g |
| 押さえ2個を含む印刷合計 | 127.98g |
| 購入部カタログ合計（r4と同じ） | 85.28g |
| **モジュール合計** | **213.26g** |
| 最低購入ロット | **$40.70** |
| 仮160円/USD＋仮3,000円/kg、試験片・サポート1.2倍込み | **約7,019円** |

実測／スライス値ではありません。r4の124.98gにローターをそのまま足してはいません。旧試験フランジと旧キャリアを除き、新形状へ置き換えた合計です。メーカーのハブ質量14gと古い仕様シート9.6gの不一致は残し、軽い方へ変更していません。

入力の金属部・ねじ・座金の購入lotは一回だけです。端リングを留める追加ねじはありません。送料・税・決済費、基台の相手材／取付ボルトは別。約2万円との差が約1.3万円あることは、未完成の下流BOMがその額に収まる証明ではありません。

## 三案の主課題へ戻るための残り

1. **入力の実抵抗・回転中供給の境界を閉じる。** 形状・質量・静的モデルと、未測定のグリース抵抗、組立バランス、空力を分離する。近いRe・縦横比・局所噴流で使えるデータがなければ、未校正モデルの反復だけで合格させない。
2. **下流の実体と公差に強い脚・同期機構を完成させる。** r3の脚は名目改善があっても±0.1mm時に足上げ・切替目標が未達。実在する国内下流部品、反力・重心・組付け・干渉・基台を同じ実CADへ統合する。本モジュールだけでA/B/Cの最終構造が確定したとはしない。
3. **同じ実BOM・入力条件で三案を再判定する。** A大径少段／B小径高減速／C中間軽量を維持し、共有購入lot・全材料費、全位相の静的／動的要求と供給、保持・支持、約30cmの実確認を揃える。現時点の合格歩行機は0案。

## 再現・検証

```sh
python3 -m unittest discover -s scripts/ver3 -p 'test_*.py' -v
/Applications/FreeCAD.app/Contents/Resources/bin/python scripts/ver3/build_wind_module.py \
  --freecad-lib /Applications/FreeCAD.app/Contents/Resources/lib \
  --vendor-dir /path/to/private-reference
python3 scripts/ver3/analyze_wind_module.py
python3 scripts/ver3/report_wind_module.py
python3 scripts/ver3/report_wind_module.py --verify
```

購入、印刷、家電操作、新しい大型ソフト導入は行っていません。別コンテキストのレビュアー1名による限定した機械・モデルレビューで、評価点の変位移送に1件の重要な修正を行いました。[是正記録](REVIEW_ja.md)には、初回レビューと、同期実行の継続制限により**調整担当の判断で別の独立レビュアーへ引き継いだR6-1限定是正確認**を区別して保存しています。同一レビュアーの追認や、全機の再承認ではありません。独立レビューは人間の有資格者による製造・運転承認でもありません。

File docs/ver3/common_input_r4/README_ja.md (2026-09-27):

# 共通入力カートリッジ — ホルダー・試験フランジの実CAD

**`v3-common-input-r4-01`。1本の入力部を実CAD化したものです。低抵抗の実証、製造リリース、三案の歩行機の完成ではありません。**

前段の [共通冷風基準の研究](../commercial_basis_r3/DESIGN_GATE_ja.md) は上書きしていません。今回は風車・歯車列・脚の探索を増やさず、既製120mm D軸、軸受2個、金属Dハブ、軸方向保持を1組に限定しました。**軸の切断・穴開け・端面タップは不要**です。

実CAD由来の入力カートリッジ

## ファイル

| 内容 | 正本 |
|---|---|
| ネイティブFreeCAD | [CommonInputR4.FCStd](../../../FreeCAD/Ver.3/common_input_r4/CommonInputR4.FCStd) |
| STEP | [CommonInputR4.step](../../../FreeCAD/Ver.3/common_input_r4/CommonInputR4.step) |
| 印刷用STL | [キャリア](../../../STL/Ver.3/common_input_r4/P_CARRIER.stl)、[押さえ×2](../../../STL/Ver.3/common_input_r4/P_CAP.stl)、[試験フランジ](../../../STL/Ver.3/common_input_r4/P_FLANGE.stl)、[フィット試験片](../../../STL/Ver.3/common_input_r4/Q_BEARING_FIT.stl) |
| 組立・部品表 | [組立手順](ASSEMBLY_ja.md)、[BOM.csv](BOM.csv)、[正規配置・手順集合](assembly.json) |
| 寸法・生成 | [input_cartridge.json](../../../scripts/ver3/input_cartridge.json)、[CAD生成](../../../scripts/ver3/build_input_cartridge.py) |
| 接触・経路 | [assembly_access.json](assembly_access.json)、[公差積層](tolerance_stack.json) |
| 質量・費用・数値 | [CAD検査](cad_validation.json)、[調達](procurement.json)、[軸の梁計算](shaft_mechanics.json)、[STL検査](stl_validation.json) |
| 版・出典・ハッシュ | [manifest.json](manifest.json) |

FreeCADは名前・部品ID・仕様・質量根拠を持つ36個のPartフィーチャです。パラメータ変更の正本はJSONと生成スクリプトで、表示用の文字プロパティを書き換えるだけで形状が追従するSketcher履歴ではありません。ネイティブ／STEPは44ソリッドで一致します。購入部の内部は**新規に作成した寸法モデル**で、メーカーの特許形状・B-rep・図面・メッシュをコピーして配布していません。

## 何が具体化したか

| 項目 | この版の結果 | まだ確認していないこと |
|---|---|---|
| キャリア | 支点・キャップ座・軸受フランジ溝・4本の本体取付穴を持つ一体形状 | 実際の造形収縮、同軸度、積層方向の強度 |
| 位置決め | **左の1軸受を2カラーと2スペーサーで挟む**。内輪積層の全すきま0.20mm | 実物の軸受内部すきま・締付後のエンドプレイ |
| 浮動 | 右外輪フランジに全2.00mm、名目±1.00mmの軸方向移動 | はめあい・支持の変形を含む実際の自由移動 |
| トルク伝達 | 6mm D軸→メーカー指定の金属Dハブ→16mm正方形の4本M4→試験フランジ | 締付条件・実伝達トルク・疲労 |
| 脱着 | 両キャップを先に組む、ハブ／フランジを先組み、軸を左から入れる経路を検査 | 指の操作性、すべての工具・誤差条件 |
| 始動抵抗 | 不要な名目接触を幾何で排除。抵抗は独立した感度入力のまま | **実部品の始動／回転抵抗値は未公表・未測定** |

## 固定側・浮動側と過締めによる予圧

実CAD断面

配置はX＝軸方向、Y＝左右、Z＝高さ。軸中心Z=30mm、支点中心X=16.5／96.5mm、支点間80mmです。

左の固定側では、外輪フランジの厚さ1.00mmに対して深さ1.30mmの空間を設けます。**3mm厚キャップはキャリア両脇の座へ着座し、軸受の面を締め付ける蓋ではありません。** 内輪側には外径約8mm・長さ4mmの既製鋼スペーサーを前後に置き、カラーの9mm径ボスと薄い蓋の干渉を避けます。正規CADではスペーサーのメーカー参照寸法6.05mm内径／7.95mm外径を用いています。

前の候補段階でカラーを左右の軸端へ1個ずつ配置した案から、**固定側の前後へ2個を集める**構成に変更しました。右軸受にカラーを追加して全体を締め上げる構成ではありません。キャリアの左右距離を、複数の内輪を通じて突っ張らせないためです。

| 名目寸法と受入シナリオ | 値 |
|---|---:|
| 固定側の外輪軸方向遊び | 0.30mm |
| 固定側の内輪＋2スペーサーに対するカラー間の全遊び | 0.20mm |
| 浮動側の外輪フランジの全移動 | 2.00mm |
| 受入仮定の端で残る固定側外輪すきま | 最小0.10mm |
| 受入仮定の端で残る片側浮動余白 | 最小0.05mm |

この計算に使ったポケット誤差±0.10mm、フランジ厚さ誤差±0.05mm、キャップ圧縮予算0.05mm等は、**実部品がその公差で届くという保証ではなく、採用する前に確認すべき設計受入条件**です。実物・材料・締付力がこれを満たさなければ再計算します。キャップが沈み込むほど締める、ガタを消すためカラーを強く押し付ける、きつい軸受をボルトで引き込む方法は取扱条件に含めません。

浮動端での円筒外周の支持長さは名目最小約2mmです。フランジにも径方向の案内がありますが、径のガタ・傾き・保持剛性まで保証したものではありません。試験片と実物の自由な移動を確認し、外輪が傾いて重くなる組合せを合格にしません。ローター荷重、歯車かみ合い、機体への取付けはこのカートリッジを全機へ組み込む次の段階です。

## Dハブは「微小交差＝不適合」でも「拡大して合格」でもない

メーカーの [1309-0016-1006](https://www.gobilda.com/1309-series-sonic-hub-6mm-d-bore/) は、6mm Dシャフトへの装着、2本の締付ねじ、分解時の解放を明示しています。この**メーカー指定の組合せ**を設計上の互換性の根拠にします。

一方、メーカーSTEPのD平面は中心から約2.48mm、軸は約2.50mmで、組付けた参照CADに約0.669mm³の微小交差があります。供給CADが開放状態か締結状態か、数値公差、締付け量の説明は確認できませんでした。**メーカー形状を拡大したり、軸を削ったことにして交差を消していません。** 交差は「メーカー指定の締付界面・状態未確認」として検査の例外表に残し、現物の挿入・締付・トルクの確認と分けます。

ハブの4本の取付穴は中心±8mmの正方形、パイロット14×2mmです。4mm厚の試験フランジ、1mm座金、M4×12によって名目ねじかかり7mm、ハブ裏面まで1mmを残します。ねじ山を省略したCADのねじ接触体積も、干渉なしのすきまばめとは呼びません。

メーカー商品ページのハブ質量14gに対して、リンク先の古い仕様シートには9.6gが記載されています。ボルト込み／本体のみの差なのか、版の差なのかは未確認です。**前報の4品目59gは14gを用いた購入アセンブリの基準値として維持し、軽い9.6gへ都合よく変更しません。**

## 小BOMと質量・費用

全て同じ入力カートリッジに使う部品です。輸入部品を全ての脚・軸へ展開する指示ではありません。クランプねじは購入カラー／ハブのアセンブリに含まれるため別途重複計上しません。

| 部品番号 | 必要数 | 購入単位 | 表示単位価格USD | 根拠 |
|---|---:|---:|---:|---|
| 2101-0006-0120、6mm D軸120mm | 1 | 1本 | 4.69 | [メーカー](https://www.gobilda.com/2101-series-stainless-steel-d-shaft-6mm-diameter-120mm-length/) |
| 1611-0514-0006、フランジ軸受 | 2 | 2個 | 3.99 | [メーカー](https://www.gobilda.com/1611-series-flanged-ball-bearing-6mm-id-x-14mm-od-5mm-thickness-2-pack/) |
| 2910-0919-0006、クランプカラー | 2 | 1個×2 | 4.49/個 | [メーカー](https://www.gobilda.com/2910-series-aluminum-clamping-collar-6mm-id-x-19mm-od-9mm-length/) |
| 1309-0016-1006、金属Dハブ | 1 | 1個 | 7.99 | [メーカー](https://www.gobilda.com/1309-series-sonic-hub-6mm-d-bore/) |
| 1521-0008-0040、4mm鋼スペーサー | 2 | 4個 | 2.49 | [メーカー](https://www.gobilda.com/1521-series-6mm-id-spacer-8mm-od-4mm-length-4-pack/) |
| 2800-0004-0012、M4×12 | 4 | 25本 | 3.59 | [メーカー](https://www.gobilda.com/m4-x-0-7mm-zinc-plated-socket-head-screw-12mm-length/) |
| 2800-0004-0020、M4×20 | 4 | 25本 | 3.99 | [メーカー](https://www.gobilda.com/m4-x-0-7mm-zinc-plated-socket-head-screw-20mm-length-25-pack/) |
| 2801-0004-0008、4×8×1mm座金 | 12 | 25枚 | 1.99 | [メーカー](https://www.gobilda.com/2801-series-zinc-plated-steel-washer-4mm-id-x-8mm-od/) |
| 2812-0004-0007、M4緩み止めナット | 4 | 25個 | 2.99 | [メーカー](https://www.gobilda.com/m4-x-0-7mm-nylock-nut/) |
| 印刷：キャリア／押さえ／フランジ | 1／2／1 | STL数量どおり | 材料価格は仮定 | [BOM](BOM.csv) |

**必要な本体数量でなく、余剰を含む最低購入ロットで $40.70**。仮140／160／180円/USDなら5,698／6,512／7,326円です。日本への送料、輸入税、為替・決済手数料は未確定で別記。基準9月27日の表示価格・購入選択肢は在庫の予約や日本到着日の保証ではありません。

| 質量 | 根拠 | 値 |
|---|---|---:|
| 前報4品目だけの小計 | 購入ページの名目値 | **59.00g** |
| 全購入品 | 上記にスペーサー・全締結品を加算 | **85.28g** |
| 印刷4実体 | 実CAD全ソリッド×仮定PETG密度1.27g/cm³ | **39.70g** |
| カートリッジ合計 | 上記2項の和 | **124.98g** |
| 実測／スライス質量 | 未実施 | **UNKNOWN** |

フィット試験片の組立数量は0で、本体質量に含みません。印刷材料単価2,000～4,000円/kg、サポート等1.2倍を仮定すると本体材料費は約95～191円ですが、実スライス値やフィラメント1巻の購入費ではありません。初回の材料費集計には別途約13gの試験片1枚も含め、`procurement.json` の `firstPrintIncludingCouponAndWasteCostJpy` で本体のみと区別しています。失敗印刷や試験片の再印刷回数は未確定です。**この小BOMを全歩行機の2万円予算達成と読み替えません。** 作業台・機体に固定する4本の取付ねじは相手材の厚さが未定のためこのカートリッジBOMの対象外です。未固定のまま運転してよい意味ではありません。

## 検査したこと

実メーカーSTEPを私的作業領域で読み、公開側の新規寸法モデルとは別に照合しました。配布物にはベンダー形状を含めません。

- 静止630組合せ、15°刻み24姿勢で回転／固定部7,560組合せを確認。ねじ界面と指定D締付界面以外の体積交差は検出しませんでした。
- 回転部対印刷部の標本最小すきまは約1.080mm。さらに全回転体のX位置−0.60／0／+0.15mm、30°刻みも確認しています。
- 左外輪の−0.30～0mm、右外輪の±1mm移動でキャリア／押さえとの体積交差は0でした。
- 前後4mmスペーサーと実メーカー内輪端面の接触面積はそれぞれ約13.91mm²でした。
- 軸受→キャップの順序、軸の左抜き、軸を抜いた後のハブ／フランジ上抜き、停止角を選んだクランプキーの上方経路を記録しています。
- ネイティブ再読込みの36オブジェクト、44ソリッド、STEP体積・配置の一致、4種類STLの閉じた単一実体と230mm以下の外接範囲を確認しました。

これは標本と記載した工具包絡の確認であり、**全連続経路、手指、あらゆる工具、実公差条件の厳密証明ではありません**。軸受の6mm穴やDクランプが実際に軽く通ることは、メーカーの指定と現物の確認が必要です。

## 要求値・抵抗・余裕を混同しない

支点間80mm、2NをX=67mmへ与える軸単体の単純支持梁スクリーニングでは、最大たわみ約0.00183mm、曲げ応力約2.11MPa。12Nmmのねじりでは角変化を約0.000102～0.000144radの剛性上下界として求めました。**D断面のねじり定数を極断面二次モーメントで代用していません。** 荷重・E/GはR3入力周辺を丸めた比較仮定で、実荷重・許容試験荷重・材料証明ではありません。

ここにはホルダー・印刷座・締結部の全体変形を含めていません。メーカーの始動／回転トルク公表値は確認できず、軸受2個で0.2／0.6／2.0Nmmという以前の値は**感度入力のまま**です。購入品を選んだことやCAD上で擦らないことから、実抵抗がその値以下だとは結論しません。

流体の正味トルク代理予測、実部品の抵抗、任意の下流2倍余裕／供給減率0.5は別項目です。このカートリッジの形状確定だけで未校正の流体値を保証値へ変えていません。

## 再生成

FreeCAD 1.1.3の既存バンドルPythonと既存のNumPy/SciPy/trimeshを使用します。メーカー部品は製品ページから個別に取得し、リポジトリ外の私的フォルダーへ `bearing.step / collar.step / shaft.step / hub.step / spacer.step` として用意する仕様です。公開されたダウンロードファイルを再配布するものではありません。

```sh
/Applications/FreeCAD.app/Contents/Resources/bin/python \
  scripts/ver3/build_input_cartridge.py \
  --freecad-lib /Applications/FreeCAD.app/Contents/Resources/lib \
  --vendor-dir /path/to/private-reference
python3 -m unittest discover -s scripts/ver3 -p 'test_input_cartridge.py' -v
python3 scripts/ver3/cartridge_report.py
python3 scripts/ver3/cartridge_report.py --verify
```

上記はデータ生成・検査で、プリンター、ドライヤー、ユーザーのライブCADシーンは操作しません。ネイティブには作成時刻等があるため、再生成時のファイルバイト不一致と幾何不一致を同一視せず、形状・配置・体積・入力ハッシュで照合します。

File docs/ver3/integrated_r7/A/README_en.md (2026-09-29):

# A: whole-machine design assessment

[日本語 (original)](README_ja.md) | **English** | [Document languages](../../../README_en.md)

> Presentation-only translation of the unchanged Japanese source. Source SHA256: `10404b22ceb7bfd9e878878c29b75603489c364f727c986b1b9e545ceca710c3`. Numbers, part IDs, equations, code and qualification limits are retained; this is not a new engineering revision.

Revision: `v3-integrated-walkers-r7-16-floor2`. **Physical starting/30 cm walking unverified; not a manufacturing release.**
See [integration review](../REVIEW_en.md) for independent stage/path review and R7-I1 correction status. Separate from geometry/performance numbers, schema 2 checks bind paths to stage inventory.

Assembly-reference drawing

|Item|Stored data|
|---|---|
|Concept direction|Large rotor, fewer stages|
|Rotor / reduction|Diameter 220 mm, capture width 32 mm, axial envelope 38 mm / 144:1|
|Nominal mass|1065.388 g: actual CAD solid volumes × assumed densities plus listed/explicitly estimated purchased-part mass|
|Reference-pose center of mass X,Y,Z|3.307, -17.021, 119.348mm|
|Purchases and initial material|JPY 23,305, excluding shipping|
|Separate costs|Shipping, unresolved taxes and unowned tools such as DN-03, about JPY 396. Separate from shared-purchase averages|
|Unresolved domestic tax / optional import-tax reserve|JPY 178 / JPY 568; not confirmed tax amounts|
|Initial coupons and assembly stand|118.36 g counted toward cost, not walking mass|
|Approved budget|About JPY 24,000 per 1 machine, approved 2026-09-28 JST by the user (relayed by parent coordinator). Shipping/unresolved taxes separate|
|Native/STEP / static / finite motion / staged insertion|PASS／PASS／PASS／PASS|
|Actual tooth-section / rotational-envelope screening|PASS for specified sections, not guaranteed continuous-angle clearance or fabrication tolerances|
|Finite tolerance/support cases|162/162, including both input-torque-couple signs and guide-friction sensitivity|

## Conditions under the same cold-air reference

Existing assumption: 6.4 m/s Gaussian peak, σ=20 mm. Not a guaranteed Panasonic/ReFa value.
Rays blocked by actual guards are excluded; pressure recovery, guard wakes and rotating aerodynamics are not modeled.
Minimum sampled stationary raw-supply proxy: **1.6166 mN·m**.
B's clockwise input uses mirrored vanes and the same offset aim above the axis to match the sign.

Cold-air velocity reference: another dryer's experiment in [Scott/Curran, ASEE2025 paper46692, §2.2/Fig.8](https://peer.asee.org/laboratory-fixture-for-heat-transfer-using-a-hair-drier.pdf).
[Panasonic EH-NE5L](https://panasonic.jp/hair/products/EH-NE5L.html) references COLD operating specifications, not a guarantee of that measured velocity.
This neither recommends nor authorizes appliance operation outside its specified use.

|Resistance sensitivity|Input demand, mN·m|Independent min/max envelope margin, mN·m|Minimum reached-phase margin, mN·m|Margin with raw supply ×0.5, mN·m|
|---|---:|---:|---:|---:|
|low|0.7787|+0.8379|+0.8379|+0.0296|
|nominal|1.4344|+0.1822|+0.1822|-0.6261|
|high|3.7101|-2.0935|-2.0934|-2.9017|

Independent envelope combines all-angle minimum supply/maximum demand. Reached-phase margin uses corresponding angles preserving actual reduction and installed phase.
These differ in meaning; the envelope is not relaxed to claim physical qualification.
low/nominal/high are unmeasured sensitivities: 0.1/0.3/1.0 mN·m per 1 bearing, sliding coefficients 0.05/0.10/0.18,
and 1-mesh efficiencies 0.95/0.90/0.80. Not demonstrated low physical resistance.

Nominal floor-slip work 47.133, guide friction 10.727,
leg-journal work 38.919 Nmm per 1 crank revolution.
Back-and-forth travel is not canceled. Spring storage/recovery enters potential energy only once.
Estimated maximum loaded-episode slip 22.27 mm; old 3 mm target remains a separate judgment.

With downstream conditions fixed nominally, total resistance of 2 input bearings must not exceed
**0.7822 mN·m**. Actual parts meeting that bound are unverified.
Prescribed RPM is not achieved RPM. Speed relationships, inertia and work residuals are in [work_budget.json](work_budget.json).
If 120 input RPM could be maintained, 30 cm corresponds to 3.90 minutes.

### Keep adverse cases separate from raw-proxy passes

|Common airflow sensitivity (assumed)|Minimum nominal-resistance margin, mN·m|
|---|---:|
|Airspeed 5.12 m/s (80% of reference)|-0.3960|
|Airspeed 7.68 m/s (120% of reference)|+0.8890|
|Jet σ=15 mm|-0.3667|
|Jet σ=25 mm|+0.6953|
|Aim 10 mm inward|+0.0169|
|Aim 10 mm outward|+0.3089|

|Assumed static rotor eccentricity, mm|Minimum adverse-eccentricity margin, mN·m|
|---:|---:|
|0.00|+0.1822|
|0.05|+0.1176|
|0.10|+0.0529|
|0.25|-0.1410|

Airspeed ±20%, jet σ=15/25 mm and inward/outward aim 10 mm are sensitivity inputs, not appliance guarantees or confidence intervals.
Support, center-of-mass/contact and loads are recalculated for each airflow condition. Eccentricity is an adverse static-gravity-torque envelope, not centrifugal-force or running-balance verification.
Raw supply ×0.5, downstream demand ×2 and UNKNOWN measured lower bound are separate judgments. [All sensitivities](environment_sensitivity.json)

## Design-specific assembly values

Main shafts: 5 mm AF, 84 mm pitch, 42-tooth synchronization gears.
The 6D input shaft (140 mm) needs no cutting/end tapping. Cut and finish domestic downstream hex stock to 100/58 mm.
Additional collar clocking: H_INPUT_COLLAR_001: -64.29°; H_INPUT_COLLAR_002: +154.29°.
Nominal static 1-plane balance, not qualification of purchased-part centers of mass, print eccentricity or dynamic balance.
See [common assembly](../ASSEMBLY_en.md) for left/right/front/rear contact surfaces and sequence.

## Complete file set

- [native](../../../../FreeCAD/Ver.3/integrated_r7/A/Walker_A.FCStd)／[STEP](../../../../FreeCAD/Ver.3/integrated_r7/A/Walker_A.step)
- [Printable STL](../../../../STL/Ver.3/integrated_r7/A) / [BOM](BOM.csv) / [minimum purchase lots](purchase_lots.json)
- [All instances/canonical parameters](assembly.json) / [static overlap](static_collisions.json) / [motion envelope](gait_motion.json) / [insertion paths](assembly_access.json)
- [Contact/tolerances](contact_sensitivity.json) / [local structure/shaft beams](structure.json) / [supply/demand](work_budget.json) / [rotating sections](rotating_clearance.json)
- [STL orientation/full-size PET templates](print_geometry.json) / [machine-readable stages](assembly_stages.json)
- [All noncontact parts/floor](floor_clearance.json) / [native enclosing envelopes](floor_envelopes.json) / [full commercial DN-03 tool access](rocker_pin_access.json)
- [Floor correction/unverified scope](../FLOOR_CORRECTION_en.md) / [5 representative slices](../SLICING_en.md)

Material anisotropy, fixed/frame-joint deformation, actual tool envelopes, print fits, real airflow and resistance require separate checks.
Part existence and finite CAD passes are distinct from physical operating qualification.

## Actual mating gear pairs in this revision

|Stage|Module, mm|Pressure angle, degrees|Teeth (input/output)|Profile shift (input/output)|
|---|---:|---:|---:|---:|
|1|1|25|12/144|+0/-0|
|2|1|25|12/144|+0/-0|

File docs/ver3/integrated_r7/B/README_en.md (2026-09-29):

# B: whole-machine design assessment

[日本語 (original)](README_ja.md) | **English** | [Document languages](../../../README_en.md)

> Presentation-only translation of the unchanged Japanese source. Source SHA256: `628136ffaf8b61f5d8f73788f7aa1d980f0bfda7ae350db7e07d2b15434e327a`. Numbers, part IDs, equations, code and qualification limits are retained; this is not a new engineering revision.

Revision: `v3-integrated-walkers-r7-16-floor2`. **Physical starting/30 cm walking unverified; not a manufacturing release.**
See [integration review](../REVIEW_en.md) for independent stage/path review and R7-I1 correction status. Separate from geometry/performance numbers, schema 2 checks bind paths to stage inventory.

Assembly-reference drawing

|Item|Stored data|
|---|---|
|Concept direction|Small rotor, high reduction / low speed|
|Rotor / reduction|Diameter 160 mm, capture width 32 mm, axial envelope 38 mm / 512:1|
|Nominal mass|1101.370 g: actual CAD solid volumes × assumed densities plus listed/explicitly estimated purchased-part mass|
|Reference-pose center of mass X,Y,Z|-0.401, -14.629, 132.758mm|
|Purchases and initial material|JPY 23,735, excluding shipping|
|Separate costs|Shipping, unresolved taxes and unowned tools such as DN-03, about JPY 396. Separate from shared-purchase averages|
|Unresolved domestic tax / optional import-tax reserve|JPY 178 / JPY 568; not confirmed tax amounts|
|Initial coupons and assembly stand|118.36 g counted toward cost, not walking mass|
|Approved budget|About JPY 24,000 per 1 machine, approved 2026-09-28 JST by the user (relayed by parent coordinator). Shipping/unresolved taxes separate|
|Native/STEP / static / finite motion / staged insertion|PASS／PASS／PASS／PASS|
|Actual tooth-section / rotational-envelope screening|PASS for specified sections, not guaranteed continuous-angle clearance or fabrication tolerances|
|Finite tolerance/support cases|162/162, including both input-torque-couple signs and guide-friction sensitivity|

## Conditions under the same cold-air reference

Existing assumption: 6.4 m/s Gaussian peak, σ=20 mm. Not a guaranteed Panasonic/ReFa value.
Rays blocked by actual guards are excluded; pressure recovery, guard wakes and rotating aerodynamics are not modeled.
Minimum sampled stationary raw-supply proxy: **1.1566 mN·m**.
B's clockwise input uses mirrored vanes and the same offset aim above the axis to match the sign.

Cold-air velocity reference: another dryer's experiment in [Scott/Curran, ASEE2025 paper46692, §2.2/Fig.8](https://peer.asee.org/laboratory-fixture-for-heat-transfer-using-a-hair-drier.pdf).
[Panasonic EH-NE5L](https://panasonic.jp/hair/products/EH-NE5L.html) references COLD operating specifications, not a guarantee of that measured velocity.
This neither recommends nor authorizes appliance operation outside its specified use.

|Resistance sensitivity|Input demand, mN·m|Independent min/max envelope margin, mN·m|Minimum reached-phase margin, mN·m|Margin with raw supply ×0.5, mN·m|
|---|---:|---:|---:|---:|
|low|0.4012|+0.7554|+0.7554|+0.1771|
|nominal|0.9422|+0.2144|+0.2144|-0.3639|
|high|2.8909|-1.7343|-1.7343|-2.3126|

Independent envelope combines all-angle minimum supply/maximum demand. Reached-phase margin uses corresponding angles preserving actual reduction and installed phase.
These differ in meaning; the envelope is not relaxed to claim physical qualification.
low/nominal/high are unmeasured sensitivities: 0.1/0.3/1.0 mN·m per 1 bearing, sliding coefficients 0.05/0.10/0.18,
and 1-mesh efficiencies 0.95/0.90/0.80. Not demonstrated low physical resistance.

Nominal floor-slip work 50.053, guide friction 11.497,
leg-journal work 39.788 Nmm per 1 crank revolution.
Back-and-forth travel is not canceled. Spring storage/recovery enters potential energy only once.
Estimated maximum loaded-episode slip 23.19 mm; old 3 mm target remains a separate judgment.

With downstream conditions fixed nominally, total resistance of 2 input bearings must not exceed
**0.8144 mN·m**. Actual parts meeting that bound are unverified.
Prescribed RPM is not achieved RPM. Speed relationships, inertia and work residuals are in [work_budget.json](work_budget.json).
If 120 input RPM could be maintained, 30 cm corresponds to 13.83 minutes.

### Keep adverse cases separate from raw-proxy passes

|Common airflow sensitivity (assumed)|Minimum nominal-resistance margin, mN·m|
|---|---:|
|Airspeed 5.12 m/s (80% of reference)|-0.2014|
|Airspeed 7.68 m/s (120% of reference)|+0.7225|
|Jet σ=15 mm|-0.1654|
|Jet σ=25 mm|+0.5416|
|Aim 10 mm inward|+0.0604|
|Aim 10 mm outward|+0.2921|

|Assumed static rotor eccentricity, mm|Minimum adverse-eccentricity margin, mN·m|
|---:|---:|
|0.00|+0.2144|
|0.05|+0.1702|
|0.10|+0.1260|
|0.25|-0.0065|

Airspeed ±20%, jet σ=15/25 mm and inward/outward aim 10 mm are sensitivity inputs, not appliance guarantees or confidence intervals.
Support, center-of-mass/contact and loads are recalculated for each airflow condition. Eccentricity is an adverse static-gravity-torque envelope, not centrifugal-force or running-balance verification.
Raw supply ×0.5, downstream demand ×2 and UNKNOWN measured lower bound are separate judgments. [All sensitivities](environment_sensitivity.json)

## Design-specific assembly values

Main shafts: 5 mm AF, 84 mm pitch, 42-tooth synchronization gears.
The 6D input shaft (140 mm) needs no cutting/end tapping. Cut and finish domestic downstream hex stock to 100/58 mm.
Additional collar clocking: H_INPUT_COLLAR_001: -64.29°; H_INPUT_COLLAR_002: +154.29°.
Nominal static 1-plane balance, not qualification of purchased-part centers of mass, print eccentricity or dynamic balance.
See [common assembly](../ASSEMBLY_en.md) for left/right/front/rear contact surfaces and sequence.

## Complete file set

- [native](../../../../FreeCAD/Ver.3/integrated_r7/B/Walker_B.FCStd)／[STEP](../../../../FreeCAD/Ver.3/integrated_r7/B/Walker_B.step)
- [Printable STL](../../../../STL/Ver.3/integrated_r7/B) / [BOM](BOM.csv) / [minimum purchase lots](purchase_lots.json)
- [All instances/canonical parameters](assembly.json) / [static overlap](static_collisions.json) / [motion envelope](gait_motion.json) / [insertion paths](assembly_access.json)
- [Contact/tolerances](contact_sensitivity.json) / [local structure/shaft beams](structure.json) / [supply/demand](work_budget.json) / [rotating sections](rotating_clearance.json)
- [STL orientation/full-size PET templates](print_geometry.json) / [machine-readable stages](assembly_stages.json)
- [All noncontact parts/floor](floor_clearance.json) / [native enclosing envelopes](floor_envelopes.json) / [full commercial DN-03 tool access](rocker_pin_access.json)
- [Floor correction/unverified scope](../FLOOR_CORRECTION_en.md) / [5 representative slices](../SLICING_en.md)

Material anisotropy, fixed/frame-joint deformation, actual tool envelopes, print fits, real airflow and resistance require separate checks.
Part existence and finite CAD passes are distinct from physical operating qualification.

### Bounded correction from final rotation check

Nominal contact between the 18-tooth pinion and M3 nut corners was found outside the static pose.
Retainer-screw half-pitch 13→14 mm was propagated from common values into cap, frame, holes, fasteners and PET templates.
Tooth form and thresholds are unchanged. Nominal minimum radial clearance 0.9746 mm, cap hole-edge material 2.75 mm and support boss 3.25 mm.
Space for required tip width 7.6 mm/thickness 1.8 mm was checked; actual commercial model/envelope and user tool fit are unverified.
Not a guarantee including physical tolerances. [Correction evidence](retainer_corner_correction.json) / [required tool check](retainer_tool_access.json)

## Actual mating gear pairs in this revision

|Stage|Module, mm|Pressure angle, degrees|Teeth (input/output)|Profile shift (input/output)|
|---|---:|---:|---:|---:|
|1|1|25|14/112|+0/-0|
|2|1|25|14/112|+0/-0|
|3|1|25|18/144|+0/-0|

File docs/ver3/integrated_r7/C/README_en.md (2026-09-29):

# C: whole-machine design assessment

[日本語 (original)](README_ja.md) | **English** | [Document languages](../../../README_en.md)

> Presentation-only translation of the unchanged Japanese source. Source SHA256: `7eb9f08eb92270fd35069ed75b254d6dbb86195eaf532cf8ab28464153e4197f`. Numbers, part IDs, equations, code and qualification limits are retained; this is not a new engineering revision.

Revision: `v3-integrated-walkers-r7-16-floor2`. **Physical starting/30 cm walking unverified; not a manufacturing release.**
See [integration review](../REVIEW_en.md) for independent stage/path review and R7-I1 correction status. Separate from geometry/performance numbers, schema 2 checks bind paths to stage inventory.

Assembly-reference drawing

|Item|Stored data|
|---|---|
|Concept direction|Intermediate diameter, lightweight frame|
|Rotor / reduction|Diameter 200 mm, capture width 32 mm, axial envelope 38 mm / 156:1|
|Nominal mass|1031.433 g: actual CAD solid volumes × assumed densities plus listed/explicitly estimated purchased-part mass|
|Reference-pose center of mass X,Y,Z|2.732, -17.103, 115.691mm|
|Purchases and initial material|JPY 23,154, excluding shipping|
|Separate costs|Shipping, unresolved taxes and unowned tools such as DN-03, about JPY 396. Separate from shared-purchase averages|
|Unresolved domestic tax / optional import-tax reserve|JPY 178 / JPY 568; not confirmed tax amounts|
|Initial coupons and assembly stand|118.36 g counted toward cost, not walking mass|
|Approved budget|About JPY 24,000 per 1 machine, approved 2026-09-28 JST by the user (relayed by parent coordinator). Shipping/unresolved taxes separate|
|Native/STEP / static / finite motion / staged insertion|PASS／PASS／PASS／PASS|
|Actual tooth-section / rotational-envelope screening|PASS for specified sections, not guaranteed continuous-angle clearance or fabrication tolerances|
|Finite tolerance/support cases|162/162, including both input-torque-couple signs and guide-friction sensitivity|

## Conditions under the same cold-air reference

Existing assumption: 6.4 m/s Gaussian peak, σ=20 mm. Not a guaranteed Panasonic/ReFa value.
Rays blocked by actual guards are excluded; pressure recovery, guard wakes and rotating aerodynamics are not modeled.
Minimum sampled stationary raw-supply proxy: **1.4629 mN·m**.
B's clockwise input uses mirrored vanes and the same offset aim above the axis to match the sign.

Cold-air velocity reference: another dryer's experiment in [Scott/Curran, ASEE2025 paper46692, §2.2/Fig.8](https://peer.asee.org/laboratory-fixture-for-heat-transfer-using-a-hair-drier.pdf).
[Panasonic EH-NE5L](https://panasonic.jp/hair/products/EH-NE5L.html) references COLD operating specifications, not a guarantee of that measured velocity.
This neither recommends nor authorizes appliance operation outside its specified use.

|Resistance sensitivity|Input demand, mN·m|Independent min/max envelope margin, mN·m|Minimum reached-phase margin, mN·m|Margin with raw supply ×0.5, mN·m|
|---|---:|---:|---:|---:|
|low|0.7163|+0.7467|+0.7468|+0.0153|
|nominal|1.3463|+0.1166|+0.1168|-0.6147|
|high|3.5359|-2.0729|-2.0725|-2.8040|

Independent envelope combines all-angle minimum supply/maximum demand. Reached-phase margin uses corresponding angles preserving actual reduction and installed phase.
These differ in meaning; the envelope is not relaxed to claim physical qualification.
low/nominal/high are unmeasured sensitivities: 0.1/0.3/1.0 mN·m per 1 bearing, sliding coefficients 0.05/0.10/0.18,
and 1-mesh efficiencies 0.95/0.90/0.80. Not demonstrated low physical resistance.

Nominal floor-slip work 44.337, guide friction 10.142,
leg-journal work 37.880 Nmm per 1 crank revolution.
Back-and-forth travel is not canceled. Spring storage/recovery enters potential energy only once.
Estimated maximum loaded-episode slip 21.77 mm; old 3 mm target remains a separate judgment.

With downstream conditions fixed nominally, total resistance of 2 input bearings must not exceed
**0.7168 mN·m**. Actual parts meeting that bound are unverified.
Prescribed RPM is not achieved RPM. Speed relationships, inertia and work residuals are in [work_budget.json](work_budget.json).
If 120 input RPM could be maintained, 30 cm corresponds to 4.22 minutes.

### Keep adverse cases separate from raw-proxy passes

|Common airflow sensitivity (assumed)|Minimum nominal-resistance margin, mN·m|
|---|---:|
|Airspeed 5.12 m/s (80% of reference)|-0.4064|
|Airspeed 7.68 m/s (120% of reference)|+0.7564|
|Jet σ=15 mm|-0.3742|
|Jet σ=25 mm|+0.5695|
|Aim 10 mm inward|-0.0430|
|Aim 10 mm outward|+0.2326|

|Assumed static rotor eccentricity, mm|Minimum adverse-eccentricity margin, mN·m|
|---:|---:|
|0.00|+0.1168|
|0.05|+0.0590|
|0.10|+0.0012|
|0.25|-0.1722|

Airspeed ±20%, jet σ=15/25 mm and inward/outward aim 10 mm are sensitivity inputs, not appliance guarantees or confidence intervals.
Support, center-of-mass/contact and loads are recalculated for each airflow condition. Eccentricity is an adverse static-gravity-torque envelope, not centrifugal-force or running-balance verification.
Raw supply ×0.5, downstream demand ×2 and UNKNOWN measured lower bound are separate judgments. [All sensitivities](environment_sensitivity.json)

## Design-specific assembly values

Main shafts: 5 mm AF, 84 mm pitch, 42-tooth synchronization gears.
The 6D input shaft (140 mm) needs no cutting/end tapping. Cut and finish domestic downstream hex stock to 100/58 mm.
Additional collar clocking: H_INPUT_COLLAR_001: -64.29°; H_INPUT_COLLAR_002: +154.29°.
Nominal static 1-plane balance, not qualification of purchased-part centers of mass, print eccentricity or dynamic balance.
See [common assembly](../ASSEMBLY_en.md) for left/right/front/rear contact surfaces and sequence.

## Complete file set

- [native](../../../../FreeCAD/Ver.3/integrated_r7/C/Walker_C.FCStd)／[STEP](../../../../FreeCAD/Ver.3/integrated_r7/C/Walker_C.step)
- [Printable STL](../../../../STL/Ver.3/integrated_r7/C) / [BOM](BOM.csv) / [minimum purchase lots](purchase_lots.json)
- [All instances/canonical parameters](assembly.json) / [static overlap](static_collisions.json) / [motion envelope](gait_motion.json) / [insertion paths](assembly_access.json)
- [Contact/tolerances](contact_sensitivity.json) / [local structure/shaft beams](structure.json) / [supply/demand](work_budget.json) / [rotating sections](rotating_clearance.json)
- [STL orientation/full-size PET templates](print_geometry.json) / [machine-readable stages](assembly_stages.json)
- [All noncontact parts/floor](floor_clearance.json) / [native enclosing envelopes](floor_envelopes.json) / [full commercial DN-03 tool access](rocker_pin_access.json)
- [Floor correction/unverified scope](../FLOOR_CORRECTION_en.md) / [5 representative slices](../SLICING_en.md)

Material anisotropy, fixed/frame-joint deformation, actual tool envelopes, print fits, real airflow and resistance require separate checks.
Part existence and finite CAD passes are distinct from physical operating qualification.

## Actual mating gear pairs in this revision

|Stage|Module, mm|Pressure angle, degrees|Teeth (input/output)|Profile shift (input/output)|
|---|---:|---:|---:|---:|
|1|0.9|20|12/156|+0.35/-0.35|
|2|1|25|12/144|+0/+0|

Do not mix C pair 1 with old C/A/B. Also read [C's 2 additional mating-part slices and supported-face warning](SLICING_en.md).

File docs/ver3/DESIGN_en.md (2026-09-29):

# Ver.3 — Design, calculation and generative-design notes

[日本語 (original)](DESIGN_ja.md) | **English** | [Document languages](../README_en.md)

> Presentation-only translation of the unchanged Japanese source. Source SHA256: `1751d32707447164ab5b30562961aa254eff08529389edfbdf06e7810b632228`. Numbers, part IDs, equations, code and qualification limits are retained; this is not a new engineering revision.

**Status: first-cut comparative prototypes with actual geometry. Not a manufacturing release or validation of wind self-starting, physical walking or fatigue life.**

This package contains FreeCAD B-rep, STEP, printable parts, BOMs, Blender visualization of the same geometry and reproducible calculations. Videos are **kinematic visualizations using prescribed input and a contact approximation**. Contact residuals and small support margins are not hidden through stretched members, arbitrary body sliding or claims of experimental validation.

## 1. Problems this design addresses

| Item | Evidence type | Ver.3 response | Remaining checks |
|---|---|---|---|
| Rotor/gears slip relative to rods instead of rotating together | Primary failure explicitly identified by the user | Geometric engagement between metal REX shaft flats and metal hubs. Plastic gears, cranks and rotor plates bolt to hubs through actual holes | Purchased-hub tightening specifications and physical slip torque |
| Gears escape axially | Reported concern | Hub fastening, shaft-end M4 bolts/washers, collars, inner-ring-only spacers, outer-ring retainers and removable guards | Shaft-end tapping, end-face contact and physical end play |
| Support friction and misalignment | Hypothesis; not established seizure | Rolling bearings, nearby supports, assembly alignment and distinct locating/floating sides for each shaft | Actual starting resistance, bore diameter/alignment and print shrinkage |
| Insufficient starting torque | Unmeasured; desktop sensitivity calculations exist | Compare rotor dimensions, stages and reduction in three designs. Treat joint static friction and each bearing's starting resistance separately | Static torque versus airspeed, direction and rotor angle |
| Leg loads vary with crank angle | Full-cycle canonical linkage calculations | Three opposing-leg modules at 0/180/0°. Report contact support and material-point residuals by phase | Ground, passive shoe joints, frame flexure and inertia |

Adhesive is not in the main torque path. Collars are **axial retention components**, not torque keys.

## 2. Formal comparison scope

| Design | Rotor outer diameter × axial width | Transmission | Aim and tradeoffs |
|---|---|---|---|
| **A: large rotor, fewer reduction stages** | 300 × 180 mm | Purchased HTD5M toothed belt 24:48 and spur gears 29:87; total **6:1** | More input area, with belt-tension adjustment, wind loading, tipping and split-rotor assembly costs |
| **B: small rotor, high reduction** | 90 × 180 mm | Three 21:84 spur stages; **64:1** | Retain a small rotor at lower speed. More stages, bearings, starting resistance and parts. Reduction does not increase input power |
| **C: intermediate rotor, generated lightweight structure** | 180 × 180 mm | Two 21:84 spur stages; **16:1** | Intermediate dimensions/stage count. Parametric generative design of rib width, thickness and layout while preserving required regions |

All spur gears use module 2, pressure angle 20° and face width 8 mm. A's primary stage is **a toothed belt, not gears**. Old single-stage or all-stages-on-one-side concepts are not mixed into adopted drawings.

See [comparison.csv](comparison.csv) and [CAD summary A](cad_validation_A.json) / [B](cad_validation_B.json) / [C](cad_validation_C.json) for solid-volume, assumed-density and purchased-mass comparisons. These are not slicer-verified print masses. Reduced infill cannot be interpreted as mass reduction without a stiffness change.

The off-center gearbox mass is addressed by **distributing stages between both ends**, not enormous shoes or arbitrary ballast. B also adjusts the axial layer of its foot triangle. Pin-to-pin linkage lengths are unchanged.

## 3. Relationship to existing records

Measurements use unscaled repository STLs and drawings. [legacy_measurements.csv](legacy_measurements.csv) stores file-coordinate bounding dimensions. STL has no inherent units; mm follows the existing documentation.

Representative file bounds: Ver.2 rotor about 90 mm diameter and 180.692 mm wide; `gear.stl` about 67.44 × 67.48 × 23 mm; `Crankshaft_Part1.stl` about 40.70 × 97.31 × 37.39 mm. These are **file bounds**, not physical measurements, tooth counts or guaranteed bore sizes. PDF shapes, dimensions and parts tables were consulted, but no complete parametric Ver.2 model exists.

The old README's 150% / legs 160% are historical settings. **Ver.3 STLs use real-size mm at 100%**; do not scale to 150% again. New linkage/bearing/hub standards mean they are not drop-in Ver.2 replacements.

## 4. Positive torque transmission and axial retention

### Purchased interfaces

- goBILDA **1309-0016-4008 Sonic Hub**: for 8 mm REX, 7 mm across flats, 32 mm outer diameter, 8 mm body, pilot diameter 14 mm × 2 mm, four M4 holes on a 16 mm square, catalog mass 14 g.
- 8 mm REX is not “8 mm hex.” It is **a 7 mm-AF hexagon with corners finished to a 8 mm circle**. CAD uses that intersection section, not a renamed round rod.
- **Relative angles** of flats and mounting holes match the purchased part. With local hole-center angles 45/135/225/315°, flat normals start at 45° in 60° increments; shaft corner reference is 15°. Opposing flipped hubs index by 90° onto the same shaft. Square mounting holes and crank phases 0/180/0° are unchanged. This corrects the draft's 15° error found by independent comparison with manufacturer CAD.
- CAD includes hub/shaft engagement flats, pilots, gear/crank mounting holes, fasteners and shaft-end stops.
- Nominal 608 bearings are 8 × 22 × 7 mm. Balls, cages, threads and special commercial-hub flexures are simplified. Purchased parts are excluded from printable STLs.

These are **dimension models of purchased parts** based on standard dimensions and public manufacturer drawings—not redistributed manufacturer CAD or drawing images. Check stock, shipping, actual tolerances, material grades and tightening torque before ordering.

REX reference angle and flipped-hub indexing

### Load path

Rotor cups → bolted forks/end plates → four M4 bolts → metal hub → REX flats → transmission stages → metal hub → crank plate → double-supported M4 pin → legs.

The crank is not one continuous main shaft: AB/AC cross the main-axis center O, so a through-shaft would collide during a cycle. Actual geometry uses **three open crank bays, paired cheeks, a 20 mm pin gap and bay-specific REX shafts**.

M4 shaft-end stops sit recessed with washers, without heads projecting into rod clearance. Countersunk cheek/hub screws sit flush.

Locating-bearing inner rings use collars/hubs and **8.1 mm ID × 10 mm OD** spacers, not simultaneous clamping of shields/outer rings. Outer rings are retained by shoulders and retainers with 20.2 mm openings. Locating outer-ring pockets are 7.2 mm; floating ones 7.7 mm. Nominal inner-ring play is 0.2 mm, to be reset by physical measurement/shims. Do not axially clamp multiple bearings end-to-end into preload.

## 5. A's toothed belt is not a lossless line

The specified purchased combination is:

| Part | Checked specification |
|---|---|
| 3411-0014-0024 | 24T, HTD5M, 14 mm bore, 12 mm width, 9.25 mm belt groove, aluminum, 23 g |
| 3415-0014-0048 | 48T, HTD5M, 14 mm bore, 12 mm width, 9.3 mm belt groove, plastic, 42 g |
| 3412-0009-0520 | HTD5M, 104 teeth, 520 mm pitch length, 9 mm width, neoprene/glass fiber |

The 24T pulley has threaded and through-holes. **Use aligned through-holes and counterbores of 7.2 mm diameter × 4 mm depth, not two threaded interfaces.** Use the specified through-holes on the 48T side.

The open-belt equation is solved with small/large pitch radii $r$/$R$ and center distance $C$.

$$
L=2\sqrt{C^2-(R-r)^2}+\pi(R+r)+2(R-r)\arcsin\frac{R-r}{C}
$$

Center distance and small-pulley wrap matching 520 mm pitch length are in [selected_designs.json](selected_designs.json). At least 8 engaged teeth is **this design's screening criterion**. Real belt tolerance/stretch requires alignment of all three input-bearing carriages with one rod and tension adjustment through **actual ±1.5 mm slots**. Intermediate shafts and spur-gear centers stay fixed.

Initial tension of 10 N per span is assumed. About 20 N radial load is included in the common 30 N frame shaft-load assumption, not ignored. Starting resistance is varied per bearing; assumed belt efficiency is 0.95. Overtightening does not create low friction.

Purchased pulley/belt teeth are **clearance/display envelopes**. Do not use them as HTD manufacturing drawings or printable tooth data; use the specified compatible purchased parts.

## 6. Spur gears and rotation directions

Involute flanks are generated mathematically, with radial root closure. This does not reproduce a hob-generated root trochoid or tooth-root fatigue analysis. Checks cover tip/root clearances, material between holes and roots, contact ratio, unshifted interference and the complete meshing cycle.

- Pressure angle 20°, no profile shift. Input tooth count is at least 21, following KHK's explanation of standard undercut limits.
- Nominal total circumferential backlash is **0.30 mm**, removing 0.15 mm from each gear. A fit-test starting point, not a printer-specific guarantee.
- Contact ratio ≥1.4, tip thickness ≥0.8 mm and hole-to-root material ≥4.5 mm are this design's screening criteria.
- A's open belt preserves direction; one spur stage reverses it. B's three spur stages reverse overall; C's two preserve direction. Canonical signs match rotor-cup orientation.
- With positive crank rotation, signed input ratios are **A −6, B −64, C +16**. Intermediate-shaft ratios appear in [validation_A.json](validation_A.json) / [B](validation_B.json) / [C](validation_C.json).

## 7. Canonical linkage and advancing scenes

Reference lengths are factual dimensions from [Frido Verweij's Jansen mechanism explanation](https://library.fridoverweij.com/codelab/strandbeest/index.html). Code and illustrations were not copied; circle-intersection equations and diagrams were implemented independently.

| Segment | Reference length | Segment | Reference length |
|---|---:|---|---:|
| QP / OQ | 38 / 7.8 | OA | 15 |
| AB / BP | 50 / 41.5 | AC / PC | 61.9 / 39.3 |
| BD / PD | 55.8 / 40.1 | CE / DE | 36.7 / 39.4 |
| CF / EF | 49 / 65.7 | Scale factor | 1.4 |

O and P are fixed, A is the crank pin and F the foot. PBD/CEF are rigid triangles. OA becomes 21 mm, allowing space for the 32 mm-diameter metal hub, pin head and tools. Left/right legs are correctly mirrored closed linkages, not simply reciprocating rods.

Canonical linkage and foot path

Full-cycle checks cover link closure, foot path, overlapping axial layers and clearance to fixed rods, auxiliary shafts and rails. Near-minimum AC/fixed-shaft-spacer clearance is also numerically minimized. Small CAD gaps are not guaranteed to survive printing.

### Walking-visualization definition

Advance derives from contact-shoe CAD vertices, support polygons and persistent material-point anchors. The whole body receives rigid transforms: **no arbitrary-speed sliding or stretched links**. All input rotors use prescribed 120 rpm.

| Design | Prescribed time for 3 crank cycles | Video duration |
|---|---:|---:|
| A | 9 s | 9 s, 1× |
| B | 96 s | 12 s, 8× |
| C | 24 s | 12 s, 2× |

This does not claim every rotor reaches 120 rpm at the same airspeed. It is **the same prescribed input** for speed comparison. Airspeed/assumed tip-speed-ratio comparisons are separately labeled calculations.

[walk_A.json](walk_A.json) / [B](walk_B.json) / [C](walk_C.json) store advance, ground gap, CAD-vertex penetration checks, support margin and material-point residuals per loaded contact episode.

The main table's slip metric is maximum horizontal displacement of a material point from its touchdown/video-start anchor within one continuous episode carrying **at least 2%** of calculated total load. **Partial episodes already active at video start are included and flagged.** Horizontal path length accumulates travel within the same episode and is a different quantity. Neither is the three-cycle total. Any ratio reports **body advance in that same episode**, not an entire cycle's distance as denominator.

| Final metrics using consistent definitions | A | B | C |
|---|---:|---:|---:|
| Maximum loaded-episode anchor residual (including initial partial episodes) | 9.55 mm | 10.30 mm | 8.88 mm |
| Maximum residual for fully contained loaded episodes only | 7.18 mm | 6.99 mm | 5.89 mm |
| All-near-foot material-point audit without load threshold (video-frame samples) | 8.90 mm | 8.54 mm | 7.56 mm |
| Maximum fully contained-episode residual in that audit | 7.16 mm | 7.03 mm | 7.35 mm |

[All-near-foot audit A](contact_review_A.json) / [B](contact_review_B.json) / [C](contact_review_C.json) tracks material points at actual video frames without excluding feet by load. Horizontal movement includes shoe rocking; it is not measured Coulomb-friction slip. The two audits use different references/sample intervals and are not mixed to claim improvement.

At least 3 geometrically near feet exist at every video sample, but during handoff only 2 feet in A/B and 1 in C may exceed the load model's 2% threshold. **This does not establish practical tripod load support at all times.** Near-contact tolerance 0.25 mm differs from display offset 0.02 mm; maximum absolute near-foot gap is about 0.269 mm.

3 mm is a demanding design-side target. Its failure is reported, not renamed a pass. The approximation uses 0.25 mm near-contact tolerance, rigid members, prescribed shoe-hinge poses and assumed masses—not ground contact dynamics, inertia, impact or actual friction.

**A positive support margin around 0.1 mm is not practical stability.** It does not adequately cover print, assembly and center-of-mass uncertainties. Sensitivity to ±5 mm center-of-mass shifts and wind tipping moments is a fixed-nominal-pose diagnostic, not guaranteed physical tipping resistance.

## 8. Torque, wind and starting resistance

All designs use common airspeeds 3/5/8 m/s, assumed torque-coefficient range 0.05–0.20 and friction conditions.

$$
T_\mathrm{wind}=\tfrac12\rho (2RL)\,R\,C_Q\,v^2
$$

Density is 1.225 kg/m³; $R$ is rotor radius and $L$ axial width. **Static torque coefficient is unmeasured** and can be zero or negative at adverse direction/rotor angles. Tables assuming positive coefficients cannot guarantee all-angle self-starting.

Compare static-friction coefficients 0.05/0.10/0.18, starting torque per bearing 0.1/0.3/1 Nmm and assumed ground-resistance coefficients 0.005/0.015/0.03. Joint reactions come from force/moment balance on each link, using journal radii and relative angular-speed ratios. **Starting friction is not collapsed into one transmission-efficiency constant.**

Nominal efficiency assumptions are 0.95 for the belt and 0.90 per spur stage. Each shaft's bearing resistance is referred to input through its actual ratio and assumed efficiencies. Friction assumptions are not selectively favorable to bearing-heavy B.

See [startup_A.json](startup_A.json) / [B](startup_B.json) / [C](startup_C.json) and [comparison summary](comparison.csv) for phase-dependent values and conditions. Available and required input are both shown. Failed starting phases are not assumed traversable by inertia once rotating. Inertia, wind pulsation and sustained rotation are unverified.

Phase-dependent input torque under common assumptions

Ground loads use the second prescribed-walking cycle at common 1° intervals. Nonnegative whole-machine load distribution does not prove static/dynamic realizability of every internal mechanism including free shoe hinges. Local leg balance is conditional on those loads. AC's simple pin-supported Euler-buckling screening ratio is only about 1.56–1.94, not a strength margin covering print tolerance, layers and fatigue.

## 9. Scope of the executed generative design

The term is **parametric generative design**. No Autodesk Generative Design, CFD, solid FEA or topology optimization is claimed.

1. Search tooth counts, shaft/support positions and left/right stage distribution within the approved rotor-size/stage scope.
2. Constrain bearing/fixed-shaft/bolt-seat preserved regions, full rotor/leg motion, through-shafts, tool/installation regions and a 256 mm print envelope.
3. Generate ribs from Delaunay connectivity; subdivide long spans with physically connected nodes/ribs, not only calculation subdivisions.
4. Use common assumed shaft load 30 N, fixed-pivot load 10 N, Young's modulus 1700 MPa and allowable stress 10 MPa.
5. Calculate an in-plane linear axial-force network and an out-of-plane 1 N cantilever approximation on the longest free rib. Screen against 0.3 mm in-plane and 0.8 mm out-of-plane displacement.
6. For C, minimize volume proxy over the declared width/thickness grid. Distinguish summed overlapping rib/boss proxies from generated CAD solid volume.

Bounds/selected values: [design.json](../../scripts/ver3/design.json), [selected_designs.json](selected_designs.json). Candidates: [gear_search.csv](gear_search.csv), [structure search A](structure_search_A.json) / [B](structure_search_B.json) / [C](structure_search_C.json).

The following compares candidates within the same C shaft positions, preserved regions and loads.

| C structural candidate | Thickness × rib width | Summed-member-volume proxy | In-plane displacement proxy | Out-of-plane displacement proxy |
|---|---:|---:|---:|---:|
| Thick-rib baseline candidate | 8 × 14 mm | 1,101,318 mm³ | 0.02198 mm | 0.38717 mm |
| Selected generated candidate | 8 × 8 mm | 713,124 mm³ | 0.03846 mm | 0.67754 mm |

Volume proxy falls about 35.25%, while displacement proxies rise. Meeting the declared displacement screens does not validate physical stiffness. This is a **summed proxy** including overlapping ribs/bosses—not a claim of 35.25% less CAD solid volume or whole-machine mass.

This is not solid analysis adequately representing local screw seats, thin walls, bearing rings, print layers, joint bending or fatigue. Frame-volume reduction is not whole-machine efficiency improvement.

## 10. Files and regeneration

| Contents | Location |
|---|---|
| Dimensions, materials and assumptions | [scripts/ver3/design.json](../../scripts/ver3/design.json) |
| Closed links, velocities and canonical transforms | [core.py](../../scripts/ver3/core.py) |
| Constrained search | [system_search.py](../../scripts/ver3/system_search.py) |
| FreeCAD generation | [build_cad.py](../../scripts/ver3/build_cad.py)、[cad_parts.py](../../scripts/ver3/cad_parts.py) |
| Native, STEP and identical visualization mesh | [FreeCAD/Ver.3](../../FreeCAD/Ver.3) |
| Printable parts only | [STL/Ver.3](../../STL/Ver.3) |
| BOM including purchased/cut parts | [A](BOM_A.csv)、[B](BOM_B.csv)、[C](BOM_C.csv) |
| Actual sections and cover templates | [drawings](drawings) |
| Results and comparisons | [comparison.csv](comparison.csv)、`validation_*.json`、`intersections_*.json` |
| Assembly and bench checks | [ASSEMBLY_ja.md](ASSEMBLY_en.md) |
| Independent review | [REVIEW_ja.md](REVIEW_en.md) |

FCStd contains native Part features with names/specifications. Canonical geometry changes require editing settings/generation scripts and regenerating; this is not a Sketcher history that follows arbitrary text-property edits.

Use existing FreeCAD/Blender installations. This work installed no new large application, made no purchases and operated no printer.

```bash
# リポジトリのルートから。通常の Python 環境には requirements.txt の依存が必要。
python3 scripts/ver3/system_search.py

# macOS の既存 FreeCAD アプリの例。環境に応じて二つのパスを変更。
FC_PY=/Applications/FreeCAD.app/Contents/Resources/bin/python
FC_LIB=/Applications/FreeCAD.app/Contents/Resources/lib
"$FC_PY" scripts/ver3/build_cad.py --freecad-lib "$FC_LIB"
"$FC_PY" scripts/ver3/check_cad.py --freecad-lib "$FC_LIB" --only A
"$FC_PY" scripts/ver3/check_cad.py --freecad-lib "$FC_LIB" --only B
"$FC_PY" scripts/ver3/check_cad.py --freecad-lib "$FC_LIB" --only C
python3 scripts/ver3/validate.py
python3 scripts/ver3/walking.py
python3 scripts/ver3/contact_report.py
python3 scripts/ver3/startup.py --only A
python3 scripts/ver3/startup.py --only B
python3 scripts/ver3/startup.py --only C
"$FC_PY" scripts/ver3/drawings.py --freecad-lib "$FC_LIB"
python3 scripts/ver3/reports.py
"$FC_PY" scripts/ver3/access_checks.py --freecad-lib "$FC_LIB"

# Blender は別のヘッドレスプロセスで実行。既存のユーザーシーンを操作しない。
# ffmpeg / ffprobe も PATH に必要。生フレームはリポジトリ外の一時領域へ。
blender --background --threads 4 --python scripts/ver3/render_blender.py -- \
  --profile system --phase all

# 再レンダリングせず、保存済みネイティブとソース・動画を照合する場合
blender --background --threads 4 --python scripts/ver3/render_blender.py -- \
  --profile system --phase validate
```

Walking JSON pins CAD/mesh/core hashes. Regenerate walking/videos after CAD changes; do not use old images as evidence for new designs.

The old `first-cut` profile in `render_blender.py` is historical experimentation, not used for the current package. Current outputs are `Blender/Ver.3/ver3_ABC.blend` and `docs/ver3/media/` in `--profile system`. `.blend` has baked prescribed walking and gear-shaft rotation, requiring no automatic Python execution to view. In B's 8× video, the input turns −240° per video frame, so even correctly unwrapped rotation may show strobing at 24 fps.

Guard/window specifications derive from each stage's `guard_depth`, `window_aperture_mm` and `window_screw_length_mm`. A's belt stage is 35 mm deep with 13 mm shaft hole and M3×40; spur stages use 31 mm, 10 mm and M3×35. Front carriers block some straight window-screw tool paths, requiring carrier-first removal/carrier-last assembly. [Installation-path checks](assembly_access_A.json) record the required partial-assembly states.

A's four additional window holes use `carriage_screw_window_points`/`carriage_screw_window_bore_mm`: **8.4 mm diameter on a 36 mm square**. They include M4 carriage screws of diameter 4 mm, adjustment ±1.5 mm and remaining radial margin 0.7 mm. They differ from 3.3 mm window-screw holes and the 13 mm rotating-shaft opening. Carrier-unit removal with the window retained is checked at adjustment extremes too.

## 11. Public evidence and pending checks

- [KHK — Involute gear profile](https://khkgears.net/new/gear_knowledge/gear_technical_reference/involute_gear_profile.html)
- [KHK — Gear dimensions](https://khkgears.net/new/gear_knowledge/gear_technical_reference/calculation_gear_dimensions.html)
- [goBILDA Sonic Hub](https://www.gobilda.com/1309-series-sonic-hub-8mm-rex-bore/)
- [goBILDA REX shafting](https://www.gobilda.com/stainless-steel-rex-shafting/)
- [24T HTD5M pulley](https://www.gobilda.com/3411-series-5mm-htd-pitch-aluminum-hub-mount-timing-belt-pulley-14mm-bore-24-tooth/)
- [48T HTD5M pulley](https://www.gobilda.com/3415-series-5mm-htd-pitch-hub-mount-timing-belt-pulley-14mm-bore-48-tooth/)
- [HTD5M belt specifications](https://www.gobilda.com/5mm-htd-timing-belts/)
- [Jansen dimensional reference](https://library.fridoverweij.com/codelab/strandbeest/index.html)
- [Autodesk — preserve geometry](https://help.autodesk.com/cloudhelp/ENU/Fusion-GenerativeDesign/files/GD-PRESERVE-GEOM.htm)
- [Autodesk — obstacle geometry, including tools and motion](https://help.autodesk.com/cloudhelp/ENU/Fusion-GenerativeDesign/files/GD-OBSTACLE-GEOM.htm)

Required physical measurements remain: crank-angle-dependent machine loads, journal/bearing starting resistance, static torque versus airspeed/direction/rotor angle, printed mass and center of mass, shaft-end retention, walking slip and tipping. Missing experiments are not filled with estimates.

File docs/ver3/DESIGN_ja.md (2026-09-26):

# Ver.3 — 設計・計算・生成設計ノート

**位置付け：実形状を伴う比較試作の第一カット。製造リリース、風力での自己始動、実機歩行、疲労寿命の確認ではありません。**

このパッケージは、FreeCAD の B-rep、STEP、印刷部品、部品表、同じ形状からの Blender 可視化と、再実行できる計算を含みます。動画は**規定入力と接地近似による運動学可視化**です。接触残差や小さい支持余裕を、部材の伸縮・任意の本体滑走・実験済みという表現で隠していません。

## 1. 何を直す設計か

| 項目 | 根拠の種類 | Ver.3 の対策 | 残る確認 |
|---|---|---|---|
| 風車・歯車と棒が滑り、一体で回らない | ユーザーが明確にした主故障 | 金属 REX 軸の平面と金属ハブの形状係合。樹脂歯車・クランク・風車板は実在する穴を通したボルトでハブへ結合 | 実購入ハブの締付仕様、実物の滑りトルク |
| 歯車が軸方向へ抜ける | 報告された懸念 | ハブ固定、軸端 M4 ボルトと座金、カラー、内輪専用スペーサ、外輪押さえ、脱着式ガード | 軸端タップ、端面接触、実物エンドプレイ |
| 支持部の摩擦・芯ずれ | 仮説。焼付きと断定しない | 転がり軸受、近接した支持、組立時の芯出し、各軸の位置決め側と逃がす側を区別 | 実際の始動抵抗、穴径・同軸度、印刷収縮 |
| 始動トルク不足 | 未測定。机上感度計算あり | 風車寸法と段数・減速比を三案で比較。関節静摩擦と各軸受の始動抵抗を別々に扱う | 風速・方位・風車角度別の静的トルク |
| クランク角で脚荷重が変わる | 正規リンクの全周計算 | 三つの対向脚モジュール、0/180/0°位相。接地支持・材料点残差を位相別に出力 | 地面、受動的な靴関節、フレームのたわみ、慣性 |

接着剤は主トルク経路にありません。カラーは**軸方向保持部品**であり、トルクキーではありません。

## 2. 三案の正式な比較範囲

| 案 | 風車外径 × 軸方向幅 | 伝達 | 狙い・代償 |
|---|---|---|---|
| **A：大風車・少段減速** | 300 × 180 mm | 購入 HTD5M 歯付きベルト 24:48 と平歯車 29:87、総減速 **6:1** | 入力面積を増やす。ベルト張力調整、風荷重、転倒、分割風車の組立が増える |
| **B：小風車・高減速** | 90 × 180 mm | 平歯車 21:84 を三段、**64:1** | 小風車を維持する代わりに低速化。段数・軸受・始動抵抗・部品数が増える。減速しても入力電力は増えない |
| **C：中間風車・生成軽量** | 180 × 180 mm | 平歯車 21:84 を二段、**16:1** | 中間寸法・段数。保存領域を守ったリブ幅・厚さ・配置のパラメトリック生成設計 |

平歯車はすべてモジュール 2、圧力角 20°、歯幅 8 mm。A の一次段は**歯車ではなく歯付きベルト**です。旧単段案や全段を片側へ集めた案は採用図に混ぜていません。

全ソリッド体積と仮定密度・購入品質量による比較値は [comparison.csv](comparison.csv) と各 [CAD 集計 A](cad_validation_A.json) / [B](cad_validation_B.json) / [C](cad_validation_C.json) を参照してください。これはスライサーで確認した印刷質量ではありません。中空率による減量を、そのまま剛性が変わらない減量と解釈してはいけません。

一方へ集めた歯車箱の重心偏りは、巨大な靴や任意バラストで隠さず、**段を左右端へ配分する配置**で対処しました。B は足三角形の軸方向レイヤー位置も調整しています。リンクのピン間長さは変えていません。

## 3. 既存資料との対応

測定対象はリポジトリ内の未拡大 STL と図面です。[legacy_measurements.csv](legacy_measurements.csv) にファイル座標の外接寸法を保存しています。STL 自体に単位情報はないため、既存資料に沿って mm と解釈しました。

代表値は、Ver.2 の風車が約 90 mm 径・180.692 mm 幅、`gear.stl` が約 67.44 × 67.48 × 23 mm、`Crankshaft_Part1.stl` が約 40.70 × 97.31 × 37.39 mm。これは**ファイルの外接寸法**であり、現物測定、歯数、軸穴の保証値ではありません。PDF の形状・寸法・部品表も参照しましたが、完全な Ver.2 パラメトリックモデルはありません。

既存 README の 150% / 脚 160% は過去の製作設定です。**Ver.3 の STL は実寸 mm、100%**。再び 150% に拡大しません。新しいリンク・軸受・ハブ規格の設計なので、Ver.2 への無加工の差替え互換性はありません。

## 4. 正のトルク伝達と軸方向保持

### 購入インターフェース

- goBILDA **1309-0016-4008 Sonic Hub**：8 mm REX 用、7 mm 対辺、外径 32 mm、本体 8 mm、直径 14 mm × 2 mm のパイロット、16 mm 正方形上の四つの M4 穴、カタログ質量 14 g。
- 8 mm REX は「8 mm 六角」ではありません。**7 mm 対辺の六角の頂点を直径 8 mm に仕上げた断面**です。CAD の軸もその交差断面で、丸棒に名前だけ付け替えていません。
- 対辺と取付穴の**相対角**も購入品に合わせています。ハブ局所面の穴中心角が45/135/225/315°のとき、対辺法線は45°から60°刻み、軸の角部基準は15°です。向かい合う反転ハブは90°インデックスして同じ軸へ合わせます。四角の取付穴とクランク0/180/0°は変えません。独立レビューのメーカー公開CAD照合で見つかった初稿の15°ずれを修正したものです。
- ハブの係合平面、軸の平面、パイロット、歯車・クランクの取付穴、締結ねじと軸端止めを CAD に設けています。
- 608 呼びの軸受は 8 × 22 × 7 mm とし、内部の玉・保持器・ねじ山・市販ハブの特殊な弾性部は簡略表示です。購入品は印刷 STL に含めません。

標準寸法とメーカーの公開図を根拠にした**購入部品の寸法モデル**です。メーカー CAD や図面画像の再配布ではありません。仕入先在庫、輸送、実物寸法公差、材料等級、締付トルクは発注前確認事項です。

REX基準角と反転側ハブのインデックス

### 荷重経路

風車カップ → ねじ止めフォーク／端板 → 四本の M4 → 金属ハブ → REX 平面 → 伝達段 → 金属ハブ → クランク板 → 両持ち M4 ピン → 脚。

クランクは一本の貫通主軸ではありません。AB・AC 棒が主軸中心 O を横切るため、貫通軸を置くと全周の途中で衝突します。**三つの開いたクランク区間、二枚の頬板、20 mm のピン間隙、区間ごとの REX 軸**を実形状で採用しました。

M4 軸端止めはワッシャを介して凹部に収め、棒が通る隙間へ頭を突出させません。頬板のハブ用ねじは皿頭を面一にしています。

位置決め軸受の内輪はカラー／ハブと **8.1 mm ID × 10 mm OD** のスペーサで扱い、シールド・外輪を一緒に挟みません。外輪は 20.2 mm 開口の肩と押さえで保持します。位置決め外輪ポケットは 7.2 mm、逃がす側は 7.7 mm。内輪の名目すきま 0.2 mm と合わせ、実物ではシムと測定で決め直します。複数軸受を端から端まで締め上げて予圧を作らないでください。

## 5. A の歯付きベルトは「無損失の線」ではない

購入指定は次の組合せです。

| 部品 | 確認した規格 |
|---|---|
| 3411-0014-0024 | 24T、HTD5M、14 mm 穴、12 mm 幅、9.25 mm ベルト溝、アルミ、23 g |
| 3415-0014-0048 | 48T、HTD5M、14 mm 穴、12 mm 幅、9.3 mm ベルト溝、樹脂、42 g |
| 3412-0009-0520 | HTD5M、104歯、520 mm ピッチ長、9 mm 幅、ネオプレン／ガラス繊維 |

24T プーリーにはねじ穴と通し穴の両方があります。**ハブと二重ねじにせず、角度を合わせた通し穴・7.2 mm 径 × 4 mm 深さの座ぐりを使用**します。48T 側は指定の通し穴を使います。

ピッチ半径を小径側 $r$、大径側 $R$、中心距離を $C$ とした開ベルトの式を解いています。

$$
L=2\sqrt{C^2-(R-r)^2}+\pi(R+r)+2(R-r)\arcsin\frac{R-r}{C}
$$

520 mm のピッチ長に合う中心距離と小径巻付きは [selected_designs.json](selected_designs.json) に数値を保存しています。小径側の係合は 8 歯以上という**本設計の基準**で確認しました。実際には長さ公差と伸びがあるので、三つの入力軸受キャリッジを同じ芯出し棒で揃え、**実在する ±1.5 mm の長穴**で張力を調整します。中間軸と平歯車中心は動かしません。

各スパンの初期張力 10 N は仮定です。約 20 N のラジアル荷重を無視せず、フレーム側の共通軸荷重仮定 30 N に含めています。始動抵抗は軸受ごとに感度計算し、ベルトの効率仮定 0.95 も明記します。締め過ぎで低摩擦になるわけではありません。

購入プーリーとベルトの歯形は**クリアランス／表示用包絡形状**です。これを HTD 歯形の製作図や印刷用データとして使わず、指定の互換購入品を使ってください。

## 6. 平歯車と回転方向

インボリュート歯面を数式から作り、根元はラジアル接続で閉じています。歯底のホブ加工トロコイドや歯元疲労解析を再現したものではありません。歯先・歯底の逃げ、取付穴から歯底までの肉、接触比、無転位干渉、全かみ合い周期を計算します。

- 圧力角 20°、無転位。KHK の標準的なアンダーカット限界の説明を参照し、入力歯数は 21 以上としました。
- 合計円周バックラッシの名目値は **0.30 mm**。両歯車から各 0.15 mm を減らしています。これはプリンター固有の保証値ではなく、フィット試験の出発点です。
- かみ合い率 1.4 以上、歯先厚 0.8 mm 以上、取付穴から歯底まで 4.5 mm 以上は本設計の選別基準です。
- A の開ベルトは同方向、平歯車一段は反転。B の三つの平歯車は合計反転、C の二段は合計同方向。正規データの符号と風車のカップ向きを合わせています。
- クランク回転を正として、入力速度比は **A −6、B −64、C +16**。中間軸の比も [validation_A.json](validation_A.json) / [B](validation_B.json) / [C](validation_C.json) に出力します。

## 7. 正規リンクと前進シーン

参考にした寸法は [Frido Verweij の Jansen 機構解説](https://library.fridoverweij.com/codelab/strandbeest/index.html) の長さという事実情報です。コードや図版はコピーせず、円の交点式と図を新規に実装しました。

| 区間 | 参考長さ | 区間 | 参考長さ |
|---|---:|---|---:|
| QP / OQ | 38 / 7.8 | OA | 15 |
| AB / BP | 50 / 41.5 | AC / PC | 61.9 / 39.3 |
| BD / PD | 55.8 / 40.1 | CE / DE | 36.7 / 39.4 |
| CF / EF | 49 / 65.7 | 拡大係数 | 1.4 |

O と P が固定側、A がクランクピン、F が足です。PBD と CEF は剛体三角形。OA は 21 mm になり、直径 32 mm の金属ハブとピン頭・工具のための空間を確保します。左右は正しく鏡映した閉リンクで、単に棒を往復させていません。

正規リンクと足軌跡

脚長の閉路、足軌跡、重なった軸方向レイヤー、固定棒・補助軸・レールとの隙間を全周で確認します。最小に近い AC と固定軸スペーサの隙間は数値最小化も行います。CAD 上の小さい隙間を、印刷後にも確実に残る隙間と解釈しないでください。

### 歩行可視化の定義

本体の前進は接地靴の CAD 頂点、支持多角形、持続する材料点アンカーから求めます。全身に剛体変換をかけ、**任意速度を足しただけの滑走やリンクの伸縮はしません**。入力風車は共通の規定値 120 rpm。

| 案 | 3クランク周期の実時間 | 動画での時間 |
|---|---:|---:|
| A | 9秒 | 9秒、1× |
| B | 96秒 | 12秒、8× |
| C | 24秒 | 12秒、2× |

これは同じ風速で各風車が 120 rpm になるという主張ではありません。速度比較のための**同じ規定入力**です。別途、風速と仮定周速比による比較も計算値として区別します。

[walk_A.json](walk_A.json) / [B](walk_B.json) / [C](walk_C.json) には、前進量、接地隙間、CAD 頂点による地面貫通検査、支持余裕、負荷を持つ接地区間ごとの材料点残差を保存します。

主表の「滑り指標」は、計算上の総荷重の **2%以上**を受け持つ一つの継続区間で、材料点が着地／動画開始時のアンカーからどれだけ水平にずれたかの最大値です。動画開始時点ですでに接触していた**部分区間も含み、そのフラグを保存**します。「水平経路長」は同じ区間での移動距離の累積で、別の量です。全三周期の合計値とも混同しません。比率を出す場合は、**同じ区間の本体前進量**を併記し、一周期全体の距離を分母にしません。

| 同一定義の最終指標 | A | B | C |
|---|---:|---:|---:|
| 荷重区間内の最大アンカー残差（開始部分区間を含む） | 9.55 mm | 10.30 mm | 8.88 mm |
| 完全に含まれる荷重区間だけでの最大残差 | 7.18 mm | 6.99 mm | 5.89 mm |
| 荷重しきい値を使わない、全近接足の材料点監査（動画フレーム標本） | 8.90 mm | 8.54 mm | 7.56 mm |
| 同監査で完全に含まれる区間の最大残差 | 7.16 mm | 7.03 mm | 7.35 mm |

[全近接足監査 A](contact_review_A.json) / [B](contact_review_B.json) / [C](contact_review_C.json) は、荷重の大小で足を除外せず、実際の動画フレームで材料点を追います。材料点の水平移動は靴の揺動も含み、実測されたクーロン摩擦の滑り量ではありません。二つの監査は基準点・標本間隔が異なり、数値を混ぜて改善と解釈しません。

幾何上の近接足は全動画標本で 3 本以上ですが、荷重配分モデルの 2% しきい値以上となる足は切替部で A/B は 2 本、C は 1 本になる瞬間があります。**常に実用的な三脚荷重支持が成立したという意味ではありません。** 近接判定 0.25 mm と地面からの表示上のオフセット 0.02 mm を区別し、全近接足の絶対隙間は最大約 0.269 mm です。

3 mm は設計側の厳しい目標です。未達を合格に言い換えず、そのまま報告します。0.25 mm の近接接地許容差、剛体部材、靴ヒンジの規定姿勢、仮定質量による近似であり、地面の接触動力学・慣性・衝撃・実摩擦を解いた動画ではありません。

**正の支持余裕が 0.1 mm 程度あっても「実用上安定」ではありません。** 印刷・組付け・重心の不確かさを十分に覆いません。重心 ±5 mm と風による転倒モーメントの感度は、名目姿勢を固定した診断として扱い、実機の転倒耐性を保証しません。

## 8. トルク、風、始動抵抗

全案で同じ風速 3 / 5 / 8 m/s、同じ仮定トルク係数範囲 0.05–0.20、同じ摩擦条件を使います。

$$
T_\mathrm{wind}=\tfrac12\rho (2RL)\,R\,C_Q\,v^2
$$

密度は 1.225 kg/m³、$R$ は風車半径、$L$ は軸方向幅です。**静的トルク係数は未測定**で、実際には不利な方位・風車角でゼロや負になることもあります。正の係数を置いた表だけで全角度自己始動を保証できません。

静摩擦係数 0.05 / 0.10 / 0.18、軸受一個の始動トルク 0.1 / 0.3 / 1 Nmm、地面抵抗の仮定係数 0.005 / 0.015 / 0.03 を比較します。各リンクの力・モーメント釣合いから関節反力を計算し、ジャーナル半径と相対角速度比を使います。**始動摩擦を伝達効率の定数一つに押し込めていません。**

ベルトは効率 0.95、平歯車は一段 0.90 が名目仮定。各軸の軸受抵抗は、その軸までの比率と仮定効率を通して入力軸に換算します。軸受数が増える B に有利な摩擦だけを選びません。

位相別値と条件は [startup_A.json](startup_A.json) / [B](startup_B.json) / [C](startup_C.json)、[比較集計](comparison.csv) を参照してください。利用可能な入力と要求入力の両方を示します。始動できない位相を、回転中なら慣性で越えられると勝手に扱いません。慣性・風の脈動・回転継続の実証は未実施です。

共通仮定による位相別入力トルク

接地荷重は規定歩行の第二周期から、全案共通の 1°間隔で採っています。全装置の非負荷重配分は、自由な靴ヒンジを含む全内部機構の静的・動的実現を証明するものではありません。脚の局所釣合いはその荷重条件付きです。AC の単純なピン支持 Euler 座屈スクリーニング比も約 1.56–1.94 に留まり、印刷公差・積層・疲労を含む強度余裕とは扱いません。

## 9. 実行した Generative Design の範囲

呼称は **パラメトリック生成設計**です。Autodesk Generative Design、CFD、ソリッド FEA、トポロジー最適化を実行したとは称しません。

1. 風車寸法・段の構成という承認範囲内で、歯数、軸位置、支持配置、左右の段配置を探索。
2. 軸受・固定軸・ボルト座の保存領域、回転体と脚の全可動域、他の貫通軸、工具／装着のための領域、256 mm 印刷枠を制約化。
3. Delaunay 接続を基にリブを作り、長い区間は実際に連結された節点・リブで細分化。単に計算上だけ分割しません。
4. 共通の仮定軸荷重 30 N、固定ピボット 10 N、ヤング率 1700 MPa、許容応力 10 MPa を使用。
5. 平面内の線形軸力ネットワークと、最長自由リブへの面外 1 N の片持ち梁近似を計算。平面内変位 0.3 mm、面外近似 0.8 mm を選別基準にする。
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

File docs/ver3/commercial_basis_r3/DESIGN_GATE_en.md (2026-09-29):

# Bounded redesign using a common commercial-dryer reference

[日本語 (original)](DESIGN_GATE_ja.md) | **English** | [Document languages](../../README_en.md)

> Presentation-only translation of the unchanged Japanese source. Source SHA256: `3d1ac38b0d92d8dc49ce1a525ea870f0dc450a73c117df2a6d03fc4cbd880368`. Numbers, part IDs, equations, code and qualification limits are retained; this is not a new engineering revision.
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

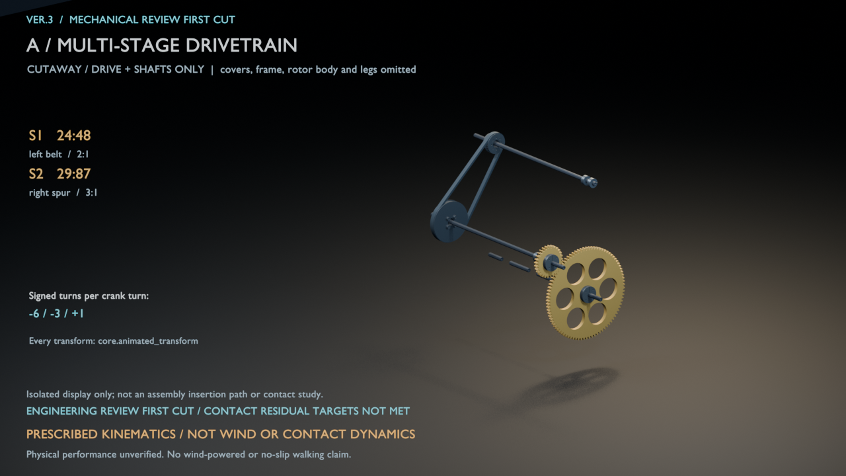
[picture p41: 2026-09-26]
docs/ver3/media/drivetrain_A.png

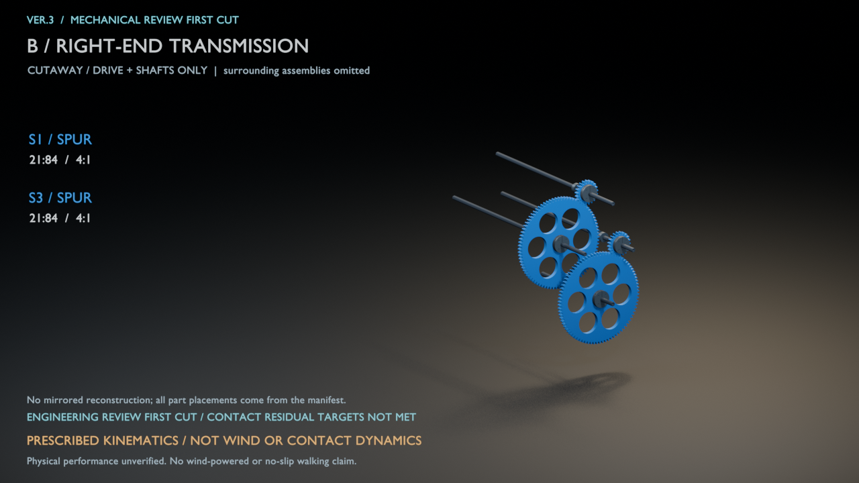
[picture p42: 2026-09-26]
docs/ver3/media/drivetrain_B_right.png

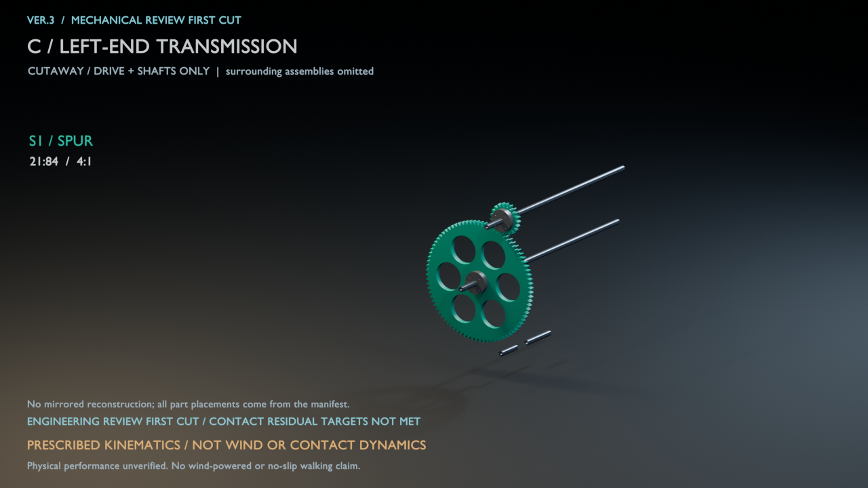
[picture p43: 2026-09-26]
docs/ver3/media/drivetrain_C_left.png

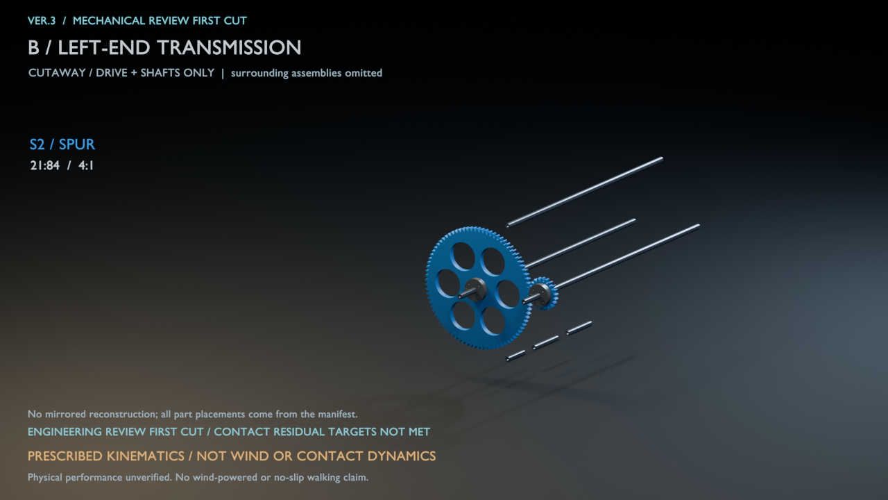
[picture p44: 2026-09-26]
docs/ver3/media/drivetrain_B_left.png

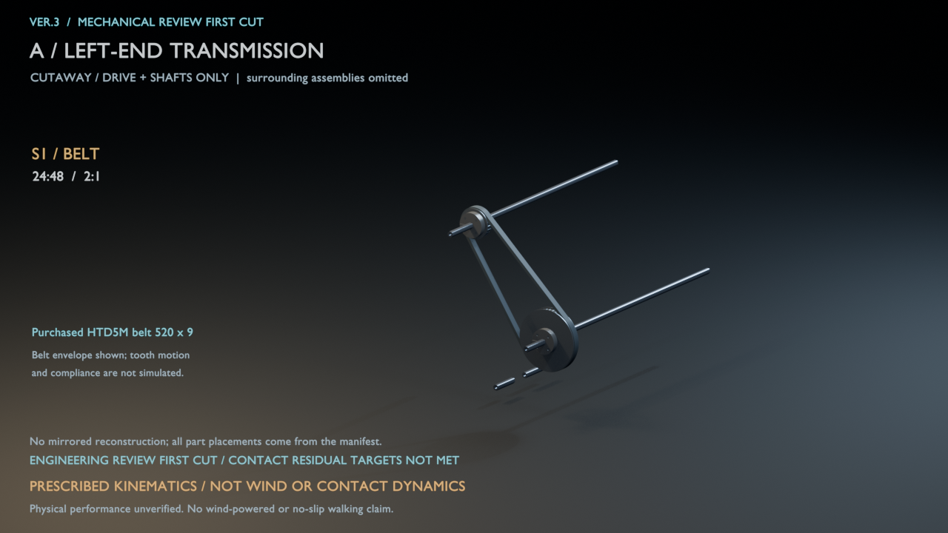
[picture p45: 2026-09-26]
docs/ver3/media/drivetrain_A_left.png

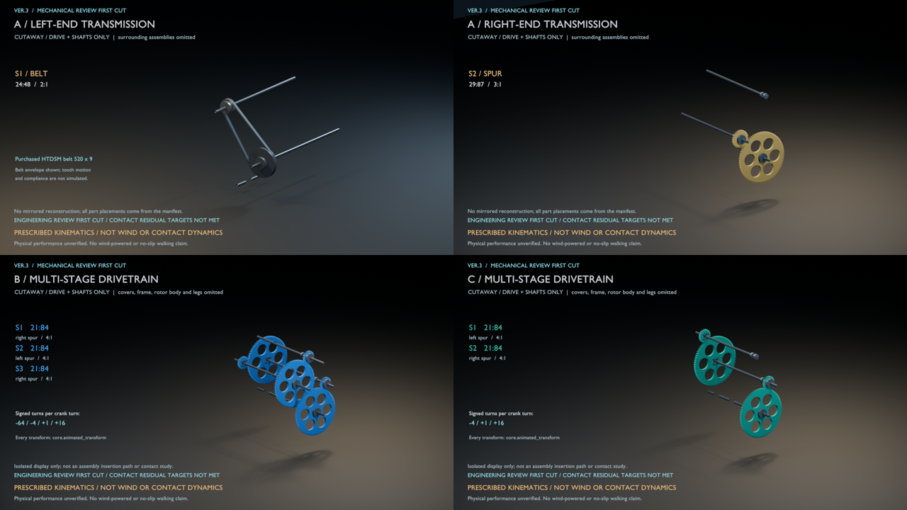
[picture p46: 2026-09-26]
docs/ver3/media/drivetrain_detail.png

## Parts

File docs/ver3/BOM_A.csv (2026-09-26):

prototype | part_id | category | quantity | specification | nominal_unit_mass_g | nominal_total_mass_g | mass_basis
A | H_608 | purchased | 12 | 608-ZZ 8x22x7; ring/ shield envelopes, assumed12g, verify actual ring faces and starting drag. | 12 | 144 | assumed unit mass
A | H_BELT520 | purchased | 1 | goBILDA3412-0009-0520, HTD5M,104teeth,520pitch length,9width; neoprene/fiberglass; CAD envelope excludes meshing-tooth detail. | 21.3404 | 21.3404 | nominal solid volume x assumed density
A | H_BODY_TIE | cut_to_length | 2 | Steel M4 threaded rod x284; simplified thread. | 28.0155 | 56.0309 | nominal solid volume x assumed density
A | H_CASE_TIE_LEFT | cut_to_length | 4 | Steel M4 case tie length96; front carrier and guard-tab supports. | 9.47 | 37.8801 | nominal solid volume x assumed density
A | H_CASE_TIE_RIGHT | cut_to_length | 4 | Steel M4 case tie length84; front carrier and guard-tab supports. | 8.2863 | 33.1451 | nominal solid volume x assumed density
A | H_COLLAR6 | purchased | 4 | Split collar6 ID, envelope16ODx8, M3 clamp; stationary pivot retention. | 9.8606 | 39.4423 | nominal solid volume x assumed density
A | H_COLLAR8 | purchased | 5 | Split collar8 ID, envelope18ODx8, M3 clamp. Axial retention only; procurement and tightening spec pending. | 11.768 | 58.8398 | nominal solid volume x assumed density
A | H_PIVOT_ROD6 | cut_to_length | 2 | Ground steel6 x282, h8 target; verify finish/straightness; supported at84 mm intervals. | 62.5909 | 125.1818 | nominal solid volume x assumed density
A | H_PULLEY24 | purchased | 1 | goBILDA3411-0014-0024;24T HTD5M,14bore,38.9flanges,12width,9.25belt channel; use unthreaded/counterbored16-square pattern (clocked45deg from threaded pattern); tooth envelope only. | 23 | 23 | catalogue
A | H_PULLEY48 | purchased | 1 | goBILDA3415-0014-0048;48T HTD5M,14bore,78.7flanges,12width,9.3channel;4mm clearance grid; simplified purchased tooth envelope. | 42 | 42 | catalogue
A | H_REX_HUB | purchased | 12 | goBILDA1309-0016-4008, REX8/7AF, 32ODx8 plus14pilotx2, 4xM4 on16square. REX corner datum15deg; reversed hub indexed90deg without moving bolt holes. Flexure and supplied clamp screws simplified. | 14 | 168 | catalogue
A | H_SOLE_STRAP | purchased | 12 | Replaceable nylon cable tie, nominal4 wide; two per sole/plate; lock head simplified; mechanical retention, not adhesive. | 0.1166 | 1.3992 | nominal solid volume x assumed density
A | H_bolt_3_10 | purchased | 24 | ISO 4762 M3x10, socket head; simplified thread | 1.0507 | 25.2158 | nominal solid volume x assumed density
A | H_bolt_3_16 | purchased | 8 | ISO 4762 M3x16, socket head; simplified thread | 1.3836 | 11.0687 | nominal solid volume x assumed density
A | H_bolt_3_20 | purchased | 6 | ISO 4762 M3x20, socket head; simplified thread | 1.6055 | 9.6332 | nominal solid volume x assumed density
A | H_bolt_3_25 | purchased | 9 | ISO 4762 M3x25, socket head; simplified thread | 1.883 | 16.9468 | nominal solid volume x assumed density
A | H_bolt_3_30 | purchased | 3 | ISO 4762 M3x30, socket head; simplified thread | 2.1604 | 6.4813 | nominal solid volume x assumed density
A | H_bolt_3_35 | purchased | 10 | ISO 4762 M3x35, socket head; simplified thread | 2.4379 | 24.3787 | nominal solid volume x assumed density
A | H_bolt_3_40 | purchased | 4 | ISO 4762 M3x40, socket head; simplified thread | 2.7153 | 10.8612 | nominal solid volume x assumed density
A | H_bolt_3_55 | purchased | 6 | ISO 4762 M3x55, socket head; simplified thread | 3.5476 | 21.2858 | nominal solid volume x assumed density
A | H_bolt_4_12 | purchased | 8 | ISO 4762 M4x12, socket head; simplified thread | 2.2698 | 18.1584 | nominal solid volume x assumed density
A | H_bolt_4_16 | purchased | 20 | ISO 4762 M4x16, socket head; simplified thread | 2.6644 | 53.2876 | nominal solid volume x assumed density
A | H_bolt_4_20 | purchased | 4 | ISO 4762 M4x20, socket head; simplified thread | 3.059 | 12.2359 | nominal solid volume x assumed density
A | H_bolt_4_45 | purchased | 3 | ISO 4762 M4x45, socket head; simplified thread | 5.5251 | 16.5753 | nominal solid volume x assumed density
A | H_button_4_8 | purchased | 12 | ISO 7380-1 M4x8; simplified thread | 1.5259 | 18.3105 | nominal solid volume x assumed density
A | H_countersunk_4_16 | purchased | 24 | ISO 10642 M4x16, 90-degree countersunk, 2.5 mm hex; flush below cheek face; simplified thread | 1.7777 | 42.6638 | nominal solid volume x assumed density
A | H_countersunk_4_30 | purchased | 12 | ISO 10642 M4x30, 90-degree countersunk, 2.5 mm hex; flush below cheek face; simplified thread | 3.1587 | 37.9044 | nominal solid volume x assumed density
A | H_crank_sleeve_4_3p2 | cut_to_length | 12 | Cut brass tube 4.2 ID x 6 OD x 3.2; crank journal/spacer | 0.3922 | 4.7067 | nominal solid volume x assumed density
A | H_crank_sleeve_4_4p7 | cut_to_length | 3 | Cut brass tube 4.2 ID x 6 OD x 4.7; crank journal/spacer | 0.5761 | 1.7282 | nominal solid volume x assumed density
A | H_endwasher_4 | purchased | 12 | Steel end-stop washer 4.2 ID x 12 OD x 0.8; positive shaft retention | 0.6232 | 7.4789 | nominal solid volume x assumed density
A | H_inner_spacer_3_1p7 | cut_to_length | 3 | Steel spacer/shim 8.1 ID x 10 OD x 1.7; INNER RING ONLY | 0.3604 | 1.0813 | nominal solid volume x assumed density
A | H_inner_spacer_3_2p6 | cut_to_length | 2 | Steel spacer/shim 8.1 ID x 10 OD x 2.6; INNER RING ONLY | 0.5513 | 1.1025 | nominal solid volume x assumed density
A | H_inner_spacer_3_3p1 | cut_to_length | 1 | Steel spacer/shim 8.1 ID x 10 OD x 3.1; INNER RING ONLY | 0.6573 | 0.6573 | nominal solid volume x assumed density
A | H_locknut_3 | purchased | 30 | ISO 10511 prevailing-torque M3 nut; simplified thread | 0.6006 | 18.0192 | nominal solid volume x assumed density
A | H_locknut_4 | purchased | 35 | ISO 10511 prevailing-torque M4 nut; simplified thread | 1.1724 | 41.0324 | nominal solid volume x assumed density
A | H_nut_3 | purchased | 40 | ISO 4032 M3 nut; simplified thread | 0.3604 | 14.4154 | nominal solid volume x assumed density
A | H_nut_4 | purchased | 8 | ISO 4032 M4 nut; simplified thread | 0.7503 | 6.0024 | nominal solid volume x assumed density
A | H_pivot_sleeve_3_3p2 | cut_to_length | 12 | Cut brass sleeve 6.1 ID x 8 OD x 3.2; stationary pivot journal | 0.5723 | 6.8677 | nominal solid volume x assumed density
A | H_pivot_sleeve_3_4p7 | cut_to_length | 3 | Cut brass sleeve 6.1 ID x 8 OD x 4.7; stationary pivot journal | 0.8406 | 2.5217 | nominal solid volume x assumed density
A | H_pivot_sleeve_3_4p8 | cut_to_length | 6 | Cut brass sleeve 6.1 ID x 8 OD x 4.8; stationary pivot journal | 0.8585 | 5.1508 | nominal solid volume x assumed density
A | H_pivot_sleeve_3_55p7 | cut_to_length | 3 | Cut brass sleeve 6.1 ID x 8 OD x 55.7; stationary pivot journal | 9.9618 | 29.8853 | nominal solid volume x assumed density
A | H_pivot_sleeve_3_59p7 | cut_to_length | 3 | Cut brass sleeve 6.1 ID x 8 OD x 59.7; stationary pivot journal | 10.6772 | 32.0315 | nominal solid volume x assumed density
A | H_pivot_sleeve_3_8p7 | cut_to_length | 3 | Cut brass sleeve 6.1 ID x 8 OD x 8.7; stationary pivot journal | 1.556 | 4.6679 | nominal solid volume x assumed density
A | H_shaft_8_111p5 | cut_to_length | 1 | 8 mm REX, 7 mm AF, corner datum15deg, cut to 111.5; M4x10 axial tapped holes both ends; machining/procurement verification pending | 35.7839 | 35.7839 | nominal solid volume x assumed density
A | H_shaft_8_372 | cut_to_length | 1 | 8 mm REX, 7 mm AF, corner datum15deg, cut to 372; M4x10 axial tapped holes both ends; machining/procurement verification pending | 122.5239 | 122.5239 | nominal solid volume x assumed density
A | H_shaft_8_37p5 | cut_to_length | 1 | 8 mm REX, 7 mm AF, corner datum15deg, cut to 37.5; M4x10 axial tapped holes both ends; machining/procurement verification pending | 11.1437 | 11.1437 | nominal solid volume x assumed density
A | H_shaft_8_408 | cut_to_length | 1 | 8 mm REX, 7 mm AF, corner datum15deg, cut to 408; M4x10 axial tapped holes both ends; machining/procurement verification pending | 134.511 | 134.511 | nominal solid volume x assumed density
A | H_shaft_8_57 | cut_to_length | 2 | 8 mm REX, 7 mm AF, corner datum15deg, cut to 57; M4x10 axial tapped holes both ends; machining/procurement verification pending | 17.6368 | 35.2735 | nominal solid volume x assumed density
A | H_sleeve_3_10 | cut_to_length | 3 | Cut brass tube 3.2 ID x 4 OD x 10, deburred; bearing journal/rigid clamp stack | 0.3845 | 1.1536 | nominal solid volume x assumed density
A | H_sleeve_3_12p3 | cut_to_length | 3 | Cut brass tube 3.2 ID x 4 OD x 12.3, deburred; bearing journal/rigid clamp stack | 0.473 | 1.4189 | nominal solid volume x assumed density
A | H_sleeve_3_37p3 | cut_to_length | 6 | Cut brass tube 3.2 ID x 4 OD x 37.3, deburred; bearing journal/rigid clamp stack | 1.4343 | 8.6058 | nominal solid volume x assumed density
A | H_sleeve_3_3p2 | cut_to_length | 60 | Cut brass tube 3.2 ID x 4 OD x 3.2, deburred; bearing journal/rigid clamp stack | 0.123 | 7.383 | nominal solid volume x assumed density
A | H_sleeve_3_4p6 | cut_to_length | 3 | Cut brass tube 3.2 ID x 4 OD x 4.6, deburred; bearing journal/rigid clamp stack | 0.1769 | 0.5307 | nominal solid volume x assumed density
A | H_sleeve_3_6p6 | cut_to_length | 3 | Cut brass tube 3.2 ID x 4 OD x 6.6, deburred; bearing journal/rigid clamp stack | 0.2538 | 0.7614 | nominal solid volume x assumed density
A | H_sleeve_3_7p3 | cut_to_length | 6 | Cut brass tube 3.2 ID x 4 OD x 7.3, deburred; bearing journal/rigid clamp stack | 0.2807 | 1.6842 | nominal solid volume x assumed density
A | H_sleeve_3_8 | cut_to_length | 3 | Cut brass tube 3.2 ID x 4 OD x 8, deburred; bearing journal/rigid clamp stack | 0.3076 | 0.9229 | nominal solid volume x assumed density
A | H_sleeve_3_8p9 | cut_to_length | 3 | Cut brass tube 3.2 ID x 4 OD x 8.9, deburred; bearing journal/rigid clamp stack | 0.3422 | 1.0267 | nominal solid volume x assumed density
A | H_tie_tube_3_14 | cut_to_length | 2 | Cut aluminium tube 6 ID x 10 OD x 14; square ends | 1.9 | 3.8001 | nominal solid volume x assumed density
A | H_tie_tube_3_36 | cut_to_length | 2 | Cut aluminium tube 6 ID x 10 OD x 36; square ends | 4.8858 | 9.7716 | nominal solid volume x assumed density
A | H_tie_tube_3_40 | cut_to_length | 2 | Cut aluminium tube 6 ID x 10 OD x 40; square ends | 5.4287 | 10.8573 | nominal solid volume x assumed density
A | H_tie_tube_3_44 | cut_to_length | 2 | Cut aluminium tube 6 ID x 10 OD x 44; square ends | 5.9715 | 11.9431 | nominal solid volume x assumed density
A | H_tie_tube_3_56 | cut_to_length | 2 | Cut aluminium tube 6 ID x 10 OD x 56; square ends | 7.6001 | 15.2003 | nominal solid volume x assumed density
A | H_tie_tube_3_6 | cut_to_length | 2 | Cut aluminium tube 6 ID x 10 OD x 6; square ends | 0.8143 | 1.6286 | nominal solid volume x assumed density
A | H_tie_tube_3_76 | cut_to_length | 6 | Cut aluminium tube 6 ID x 10 OD x 76; square ends | 10.3145 | 61.8869 | nominal solid volume x assumed density
A | H_washer_3_0p5 | purchased | 118 | Washer 3.2 ID x 7 OD x 0.5; verify purchased thickness | 0.1195 | 14.0992 | nominal solid volume x assumed density
A | H_washer_4_0p5 | purchased | 15 | Washer 4.2 ID x 9 OD x 0.5; verify purchased thickness | 0.1953 | 2.9298 | nominal solid volume x assumed density
A | H_washer_4_0p8 | purchased | 66 | Washer 4.2 ID x 9 OD x 0.8; verify purchased thickness | 0.3125 | 20.6257 | nominal solid volume x assumed density
A | L_AB | printed | 6 | PETG Jansen L_AB; thickness3, web8; P bore8.2, A bore6.2, other joints4.2; mirrored triangles have_R suffix. | 2.1741 | 13.0448 | nominal solid volume x assumed density
A | L_AC | printed | 6 | PETG Jansen L_AC; thickness3, web7.5; P bore8.2, A bore6.2, other joints4.2; mirrored triangles have_R suffix. | 2.5164 | 15.0982 | nominal solid volume x assumed density
A | L_CEF | printed | 3 | PETG Jansen L_CEF; thickness3, web8; P bore8.2, A bore6.2, other joints4.2; mirrored triangles have_R suffix. | 5.9561 | 17.8684 | nominal solid volume x assumed density
A | L_CEF_R | printed | 3 | PETG Jansen L_CEF_R; thickness3, web8; P bore8.2, A bore6.2, other joints4.2; mirrored triangles have_R suffix. | 5.9561 | 17.8684 | nominal solid volume x assumed density
A | L_DE | printed | 6 | PETG Jansen L_DE; thickness3, web8; P bore8.2, A bore6.2, other joints4.2; mirrored triangles have_R suffix. | 1.7255 | 10.3528 | nominal solid volume x assumed density
A | L_PBD | printed | 3 | PETG Jansen L_PBD; thickness3, web8; P bore8.2, A bore6.2, other joints4.2; mirrored triangles have_R suffix. | 5.4686 | 16.4057 | nominal solid volume x assumed density
A | L_PBD_R | printed | 3 | PETG Jansen L_PBD_R; thickness3, web8; P bore8.2, A bore6.2, other joints4.2; mirrored triangles have_R suffix. | 5.4686 | 16.4057 | nominal solid volume x assumed density
A | L_PC | printed | 6 | PETG Jansen L_PC; thickness3, web8; P bore8.2, A bore6.2, other joints4.2; mirrored triangles have_R suffix. | 1.8592 | 11.1552 | nominal solid volume x assumed density
A | P_BEARING_RETAINER | printed | 12 | 44ODx2,20.2aperture,twoM3 on32PCD; outer ring only. | 2.9337 | 35.2046 | nominal solid volume x assumed density
A | P_CRANK_CHEEK | printed | 6 | 8 thick, crank21; metal flange4M4x16 countersunk; recessed M4 shaft end stops; M4 shared crank pin. | 8.7269 | 52.3613 | nominal solid volume x assumed density
A | P_FRAME_CORE | printed | 2 | PETG 8 thick x14 ribs; actual preserve seats/bolt holes; core; 22.2 bearing seats, 20.2 outer-ring shoulders. | 71.0565 | 142.1129 | nominal solid volume x assumed density
A | P_FRAME_FRONT_LEFT | printed | 1 | PETG 8 thick x14 ribs; actual preserve seats/bolt holes; front_left; 22.2 bearing seats, 20.2 outer-ring shoulders. | 115.5547 | 115.5547 | nominal solid volume x assumed density
A | P_FRAME_FRONT_RIGHT | printed | 1 | PETG 8 thick x14 ribs; actual preserve seats/bolt holes; front_right; 22.2 bearing seats, 20.2 outer-ring shoulders. | 143.0748 | 143.0748 | nominal solid volume x assumed density
A | P_FRAME_LEFT | printed | 1 | PETG 8 thick x14 ribs; actual preserve seats/bolt holes; left; 22.2 bearing seats, 20.2 outer-ring shoulders. | 260.7298 | 260.7298 | nominal solid volume x assumed density
A | P_FRAME_RIGHT | printed | 1 | PETG 8 thick x14 ribs; actual preserve seats/bolt holes; right; 22.2 bearing seats, 20.2 outer-ring shoulders. | 267.9912 | 267.9912 | nominal solid volume x assumed density
A | P_GUARD_1 | printed | 1 | Per-stage guard35 deep,2back/2.5walls, two chassis-rod tabs, rear-accessible captiveM3 cover nuts; not certified containment. | 175.8512 | 175.8512 | nominal solid volume x assumed density
A | P_GUARD_2 | printed | 1 | Per-stage guard31 deep,2back/2.5walls, two chassis-rod tabs, rear-accessible captiveM3 cover nuts; not certified containment. | 198.6707 | 198.6707 | nominal solid volume x assumed density
A | P_INPUT_CARRIAGE_FLOAT | printed | 2 | 48x48x8 input bearing carriage, fourM4 countersunk mounts in real +/-1.5mm frame slots; align all3 carriages together before tensioning. | 17.9563 | 35.9125 | nominal solid volume x assumed density
A | P_INPUT_CARRIAGE_LOC | printed | 1 | 48x48x8 input bearing carriage, fourM4 countersunk mounts in real +/-1.5mm frame slots; align all3 carriages together before tensioning. | 17.9975 | 17.9975 | nominal solid volume x assumed density
A | P_ROTOR_CORE | printed | 1 | Rotor core/endplate5 thick,14.2pilot,4M4 mounting; opposite end has mirrored hole pattern. | 29.8147 | 29.8147 | nominal solid volume x assumed density
A | P_ROTOR_CORE_R | printed | 1 | Rotor core/endplate5 thick,14.2pilot,4M4 mounting; opposite end has mirrored hole pattern. | 29.8147 | 29.8147 | nominal solid volume x assumed density
A | P_ROTOR_CUP | printed | 2 | Scoop for diameter300, span180, wall2.4; shaft clearance10; open-access M3 nuts. | 122.1094 | 244.2188 | nominal solid volume x assumed density
A | P_ROTOR_YOKE | printed | 2 | One fused fork per cup/end, thickness8,width16; twoM4 root fasteners and twoM3 cup fasteners; no overlapping separate spokes. | 26.9676 | 53.9353 | nominal solid volume x assumed density
A | P_ROTOR_YOKE_R | printed | 2 | One fused fork per cup/end, thickness8,width16; twoM4 root fasteners and twoM3 cup fasteners; no overlapping separate spokes. | 26.9676 | 53.9353 | nominal solid volume x assumed density
A | P_S2_PINION | printed | 1 | Involute20deg,m2.0,z29,8face,pair backlash0.30;4M4 bolted REX hub; phase follows actual stage axis vector. | 23.4641 | 23.4641 | nominal solid volume x assumed density
A | P_S2_WHEEL | printed | 1 | Involute20deg,m2.0,z87,8face,pair backlash0.30;4M4 bolted REX hub; phase follows actual stage axis vector. | 148.9092 | 148.9092 | nominal solid volume x assumed density
A | P_SHOE | printed | 6 | PETG shoe40.0x18.0x5.0, free M3/4mm-bush pitch hinge; replaceable sole; foot dimensions include drivetrain COG/foot-sweep tradeoff. | 5.004 | 30.024 | nominal solid volume x assumed density
A | Q_BEARING_FIT | printed | 0 | Separate21.9/22.1/22.3 bearing seat coupon; assembly quantity0. | 17.9759 | 0.0 | nominal solid volume x assumed density
A | Q_JOINT_FIT | printed | 0 | Separate4.0/4.2/6.0/6.2/8.2 bore coupon; assembly quantity0. | 9.5127 | 0.0 | nominal solid volume x assumed density
A | S_SOLE | cut_to_length | 6 | Rubber/foam sole40.0x18.0x3; two4.2-wide,0.5-deep strap recesses; grip/compliance unmeasured; density0.8 assumed. | 1.6675 | 10.0051 | nominal solid volume x assumed density
A | S_WINDOW_1 | cut_to_length | 1 | Clear PETG sheet1, cut/drill from CAD, fourM3x40,13shaft apertures; not a printed part. Four additional8.4mm carriage-screw clearance holes on36mm square around input axis, including +/-1.5mm adjustment. | 47.3859 | 47.3859 | nominal solid volume x assumed density
A | S_WINDOW_2 | cut_to_length | 1 | Clear PETG sheet1, cut/drill from CAD, fourM3x35,10shaft apertures; not a printed part. | 60.8663 | 60.8663 | nominal solid volume x assumed density

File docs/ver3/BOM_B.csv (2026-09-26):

prototype | part_id | category | quantity | specification | nominal_unit_mass_g | nominal_total_mass_g | mass_basis
B | H_608 | purchased | 16 | 608-ZZ 8x22x7; ring/ shield envelopes, assumed12g, verify actual ring faces and starting drag. | 12 | 192 | assumed unit mass
B | H_BODY_TIE | cut_to_length | 2 | Steel M4 threaded rod x284; simplified thread. | 28.0155 | 56.0309 | nominal solid volume x assumed density
B | H_CASE_TIE_LEFT | cut_to_length | 4 | Steel M4 case tie length84; front carrier and guard-tab supports. | 8.2863 | 33.1451 | nominal solid volume x assumed density
B | H_CASE_TIE_RIGHT | cut_to_length | 4 | Steel M4 case tie length124; front carrier and guard-tab supports. | 12.2321 | 48.9284 | nominal solid volume x assumed density
B | H_COLLAR6 | purchased | 4 | Split collar6 ID, envelope16ODx8, M3 clamp; stationary pivot retention. | 9.8606 | 39.4423 | nominal solid volume x assumed density
B | H_COLLAR8 | purchased | 7 | Split collar8 ID, envelope18ODx8, M3 clamp. Axial retention only; procurement and tightening spec pending. | 11.768 | 82.3757 | nominal solid volume x assumed density
B | H_PIVOT_ROD6 | cut_to_length | 2 | Ground steel6 x284, h8 target; verify finish/straightness; supported at84 mm intervals. | 63.0348 | 126.0696 | nominal solid volume x assumed density
B | H_REX_HUB | purchased | 14 | goBILDA1309-0016-4008, REX8/7AF, 32ODx8 plus14pilotx2, 4xM4 on16square. REX corner datum15deg; reversed hub indexed90deg without moving bolt holes. Flexure and supplied clamp screws simplified. | 14 | 196 | catalogue
B | H_SOLE_STRAP | purchased | 12 | Replaceable nylon cable tie, nominal4 wide; two per sole/plate; lock head simplified; mechanical retention, not adhesive. | 0.1166 | 1.3992 | nominal solid volume x assumed density
B | H_bolt_3_12 | purchased | 40 | ISO 4762 M3x12, socket head; simplified thread | 1.1616 | 46.4654 | nominal solid volume x assumed density
B | H_bolt_3_20 | purchased | 6 | ISO 4762 M3x20, socket head; simplified thread | 1.6055 | 9.6332 | nominal solid volume x assumed density
B | H_bolt_3_25 | purchased | 3 | ISO 4762 M3x25, socket head; simplified thread | 1.883 | 5.6489 | nominal solid volume x assumed density
B | H_bolt_3_30 | purchased | 9 | ISO 4762 M3x30, socket head; simplified thread | 2.1604 | 19.4438 | nominal solid volume x assumed density
B | H_bolt_3_35 | purchased | 12 | ISO 4762 M3x35, socket head; simplified thread | 2.4379 | 29.2544 | nominal solid volume x assumed density
B | H_bolt_3_55 | purchased | 6 | ISO 4762 M3x55, socket head; simplified thread | 3.5476 | 21.2858 | nominal solid volume x assumed density
B | H_bolt_3_65 | purchased | 6 | ISO 4762 M3x65, socket head; simplified thread | 4.1025 | 24.6151 | nominal solid volume x assumed density
B | H_bolt_4_12 | purchased | 8 | ISO 4762 M4x12, socket head; simplified thread | 2.2698 | 18.1584 | nominal solid volume x assumed density
B | H_bolt_4_16 | purchased | 24 | ISO 4762 M4x16, socket head; simplified thread | 2.6644 | 63.9451 | nominal solid volume x assumed density
B | H_bolt_4_45 | purchased | 3 | ISO 4762 M4x45, socket head; simplified thread | 5.5251 | 16.5753 | nominal solid volume x assumed density
B | H_button_4_8 | purchased | 14 | ISO 7380-1 M4x8; simplified thread | 1.5259 | 21.3623 | nominal solid volume x assumed density
B | H_countersunk_4_16 | purchased | 24 | ISO 10642 M4x16, 90-degree countersunk, 2.5 mm hex; flush below cheek face; simplified thread | 1.7777 | 42.6638 | nominal solid volume x assumed density
B | H_crank_sleeve_4_3p2 | cut_to_length | 12 | Cut brass tube 4.2 ID x 6 OD x 3.2; crank journal/spacer | 0.3922 | 4.7067 | nominal solid volume x assumed density
B | H_crank_sleeve_4_4p7 | cut_to_length | 3 | Cut brass tube 4.2 ID x 6 OD x 4.7; crank journal/spacer | 0.5761 | 1.7282 | nominal solid volume x assumed density
B | H_endwasher_4 | purchased | 14 | Steel end-stop washer 4.2 ID x 12 OD x 0.8; positive shaft retention | 0.6232 | 8.7254 | nominal solid volume x assumed density
B | H_inner_spacer_3_1p7 | cut_to_length | 3 | Steel spacer/shim 8.1 ID x 10 OD x 1.7; INNER RING ONLY | 0.3604 | 1.0813 | nominal solid volume x assumed density
B | H_inner_spacer_3_2p6 | cut_to_length | 3 | Steel spacer/shim 8.1 ID x 10 OD x 2.6; INNER RING ONLY | 0.5513 | 1.6538 | nominal solid volume x assumed density
B | H_inner_spacer_3_3p1 | cut_to_length | 1 | Steel spacer/shim 8.1 ID x 10 OD x 3.1; INNER RING ONLY | 0.6573 | 0.6573 | nominal solid volume x assumed density
B | H_inner_spacer_3_3p7 | cut_to_length | 1 | Steel spacer/shim 8.1 ID x 10 OD x 3.7; INNER RING ONLY | 0.7845 | 0.7845 | nominal solid volume x assumed density
B | H_locknut_3 | purchased | 30 | ISO 10511 prevailing-torque M3 nut; simplified thread | 0.6006 | 18.0192 | nominal solid volume x assumed density
B | H_locknut_4 | purchased | 23 | ISO 10511 prevailing-torque M4 nut; simplified thread | 1.1724 | 26.9641 | nominal solid volume x assumed density
B | H_nut_3 | purchased | 52 | ISO 4032 M3 nut; simplified thread | 0.3604 | 18.74 | nominal solid volume x assumed density
B | H_pivot_sleeve_3_3p2 | cut_to_length | 12 | Cut brass sleeve 6.1 ID x 8 OD x 3.2; stationary pivot journal | 0.5723 | 6.8677 | nominal solid volume x assumed density
B | H_pivot_sleeve_3_4p7 | cut_to_length | 3 | Cut brass sleeve 6.1 ID x 8 OD x 4.7; stationary pivot journal | 0.8406 | 2.5217 | nominal solid volume x assumed density
B | H_pivot_sleeve_3_4p8 | cut_to_length | 6 | Cut brass sleeve 6.1 ID x 8 OD x 4.8; stationary pivot journal | 0.8585 | 5.1508 | nominal solid volume x assumed density
B | H_pivot_sleeve_3_53p7 | cut_to_length | 3 | Cut brass sleeve 6.1 ID x 8 OD x 53.7; stationary pivot journal | 9.6041 | 28.8122 | nominal solid volume x assumed density
B | H_pivot_sleeve_3_57p7 | cut_to_length | 3 | Cut brass sleeve 6.1 ID x 8 OD x 57.7; stationary pivot journal | 10.3195 | 30.9584 | nominal solid volume x assumed density
B | H_pivot_sleeve_3_8p7 | cut_to_length | 3 | Cut brass sleeve 6.1 ID x 8 OD x 8.7; stationary pivot journal | 1.556 | 4.6679 | nominal solid volume x assumed density
B | H_shaft_8_151p5 | cut_to_length | 1 | 8 mm REX, 7 mm AF, corner datum15deg, cut to 151.5; M4x10 axial tapped holes both ends; machining/procurement verification pending | 49.1029 | 49.1029 | nominal solid volume x assumed density
B | H_shaft_8_386 | cut_to_length | 1 | 8 mm REX, 7 mm AF, corner datum15deg, cut to 386; M4x10 axial tapped holes both ends; machining/procurement verification pending | 127.1855 | 127.1855 | nominal solid volume x assumed density
B | H_shaft_8_39p5 | cut_to_length | 1 | 8 mm REX, 7 mm AF, corner datum15deg, cut to 39.5; M4x10 axial tapped holes both ends; machining/procurement verification pending | 11.8097 | 11.8097 | nominal solid volume x assumed density
B | H_shaft_8_438 | cut_to_length | 2 | 8 mm REX, 7 mm AF, corner datum15deg, cut to 438; M4x10 axial tapped holes both ends; machining/procurement verification pending | 144.5002 | 289.0005 | nominal solid volume x assumed density
B | H_shaft_8_57 | cut_to_length | 2 | 8 mm REX, 7 mm AF, corner datum15deg, cut to 57; M4x10 axial tapped holes both ends; machining/procurement verification pending | 17.6368 | 35.2735 | nominal solid volume x assumed density
B | H_sleeve_3_12p3 | cut_to_length | 3 | Cut brass tube 3.2 ID x 4 OD x 12.3, deburred; bearing journal/rigid clamp stack | 0.473 | 1.4189 | nominal solid volume x assumed density
B | H_sleeve_3_15p3 | cut_to_length | 6 | Cut brass tube 3.2 ID x 4 OD x 15.3, deburred; bearing journal/rigid clamp stack | 0.5883 | 3.53 | nominal solid volume x assumed density
B | H_sleeve_3_36p6 | cut_to_length | 3 | Cut brass tube 3.2 ID x 4 OD x 36.6, deburred; bearing journal/rigid clamp stack | 1.4074 | 4.2221 | nominal solid volume x assumed density
B | H_sleeve_3_37p3 | cut_to_length | 6 | Cut brass tube 3.2 ID x 4 OD x 37.3, deburred; bearing journal/rigid clamp stack | 1.4343 | 8.6058 | nominal solid volume x assumed density
B | H_sleeve_3_3p2 | cut_to_length | 60 | Cut brass tube 3.2 ID x 4 OD x 3.2, deburred; bearing journal/rigid clamp stack | 0.123 | 7.383 | nominal solid volume x assumed density
B | H_sleeve_3_40 | cut_to_length | 3 | Cut brass tube 3.2 ID x 4 OD x 40, deburred; bearing journal/rigid clamp stack | 1.5381 | 4.6144 | nominal solid volume x assumed density
B | H_sleeve_3_4p6 | cut_to_length | 3 | Cut brass tube 3.2 ID x 4 OD x 4.6, deburred; bearing journal/rigid clamp stack | 0.1769 | 0.5307 | nominal solid volume x assumed density
B | H_sleeve_3_8 | cut_to_length | 3 | Cut brass tube 3.2 ID x 4 OD x 8, deburred; bearing journal/rigid clamp stack | 0.3076 | 0.9229 | nominal solid volume x assumed density
B | H_sleeve_3_8p9 | cut_to_length | 3 | Cut brass tube 3.2 ID x 4 OD x 8.9, deburred; bearing journal/rigid clamp stack | 0.3422 | 1.0267 | nominal solid volume x assumed density
B | H_tie_tube_3_35 | cut_to_length | 4 | Cut aluminium tube 6 ID x 10 OD x 35; square ends | 4.7501 | 19.0004 | nominal solid volume x assumed density
B | H_tie_tube_3_42 | cut_to_length | 2 | Cut aluminium tube 6 ID x 10 OD x 42; square ends | 5.7001 | 11.4002 | nominal solid volume x assumed density
B | H_tie_tube_3_45 | cut_to_length | 2 | Cut aluminium tube 6 ID x 10 OD x 45; square ends | 6.1073 | 12.2145 | nominal solid volume x assumed density
B | H_tie_tube_3_5 | cut_to_length | 4 | Cut aluminium tube 6 ID x 10 OD x 5; square ends | 0.6786 | 2.7143 | nominal solid volume x assumed density
B | H_tie_tube_3_74 | cut_to_length | 6 | Cut aluminium tube 6 ID x 10 OD x 74; square ends | 10.043 | 60.2583 | nominal solid volume x assumed density
B | H_tie_tube_3_75 | cut_to_length | 2 | Cut aluminium tube 6 ID x 10 OD x 75; square ends | 10.1788 | 20.3575 | nominal solid volume x assumed density
B | H_washer_3_0p5 | purchased | 122 | Washer 3.2 ID x 7 OD x 0.5; verify purchased thickness | 0.1195 | 14.5772 | nominal solid volume x assumed density
B | H_washer_4_0p5 | purchased | 15 | Washer 4.2 ID x 9 OD x 0.5; verify purchased thickness | 0.1953 | 2.9298 | nominal solid volume x assumed density
B | H_washer_4_0p8 | purchased | 58 | Washer 4.2 ID x 9 OD x 0.8; verify purchased thickness | 0.3125 | 18.1256 | nominal solid volume x assumed density
B | L_AB | printed | 6 | PETG Jansen L_AB; thickness3, web8; P bore8.2, A bore6.2, other joints4.2; mirrored triangles have_R suffix. | 2.1741 | 13.0448 | nominal solid volume x assumed density
B | L_AC | printed | 6 | PETG Jansen L_AC; thickness3, web7.5; P bore8.2, A bore6.2, other joints4.2; mirrored triangles have_R suffix. | 2.5164 | 15.0982 | nominal solid volume x assumed density
B | L_CEF | printed | 3 | PETG Jansen L_CEF; thickness3, web8; P bore8.2, A bore6.2, other joints4.2; mirrored triangles have_R suffix. | 5.9561 | 17.8684 | nominal solid volume x assumed density
B | L_CEF_R | printed | 3 | PETG Jansen L_CEF_R; thickness3, web8; P bore8.2, A bore6.2, other joints4.2; mirrored triangles have_R suffix. | 5.9561 | 17.8684 | nominal solid volume x assumed density
B | L_DE | printed | 6 | PETG Jansen L_DE; thickness3, web8; P bore8.2, A bore6.2, other joints4.2; mirrored triangles have_R suffix. | 1.7255 | 10.3528 | nominal solid volume x assumed density
B | L_PBD | printed | 3 | PETG Jansen L_PBD; thickness3, web8; P bore8.2, A bore6.2, other joints4.2; mirrored triangles have_R suffix. | 5.4686 | 16.4057 | nominal solid volume x assumed density
B | L_PBD_R | printed | 3 | PETG Jansen L_PBD_R; thickness3, web8; P bore8.2, A bore6.2, other joints4.2; mirrored triangles have_R suffix. | 5.4686 | 16.4057 | nominal solid volume x assumed density
B | L_PC | printed | 6 | PETG Jansen L_PC; thickness3, web8; P bore8.2, A bore6.2, other joints4.2; mirrored triangles have_R suffix. | 1.8592 | 11.1552 | nominal solid volume x assumed density
B | P_BEARING_RETAINER | printed | 16 | 44ODx2,20.2aperture,twoM3 on32PCD; outer ring only. | 2.9337 | 46.9395 | nominal solid volume x assumed density
B | P_CRANK_CHEEK | printed | 6 | 8 thick, crank21; metal flange4M4x16 countersunk; recessed M4 shaft end stops; M4 shared crank pin. | 8.7269 | 52.3613 | nominal solid volume x assumed density
B | P_FRAME_CORE | printed | 2 | PETG 10 thick x14 ribs; actual preserve seats/bolt holes; core; 22.2 bearing seats, 20.2 outer-ring shoulders. | 81.632 | 163.264 | nominal solid volume x assumed density
B | P_FRAME_FRONT_LEFT | printed | 1 | PETG 10 thick x14 ribs; actual preserve seats/bolt holes; front_left; 22.2 bearing seats, 20.2 outer-ring shoulders. | 101.8184 | 101.8184 | nominal solid volume x assumed density
B | P_FRAME_FRONT_RIGHT | printed | 1 | PETG 10 thick x14 ribs; actual preserve seats/bolt holes; front_right; 22.2 bearing seats, 20.2 outer-ring shoulders. | 276.6302 | 276.6302 | nominal solid volume x assumed density
B | P_FRAME_LEFT | printed | 1 | PETG 10 thick x14 ribs; actual preserve seats/bolt holes; left; 22.2 bearing seats, 20.2 outer-ring shoulders. | 303.5135 | 303.5135 | nominal solid volume x assumed density
B | P_FRAME_RIGHT | printed | 1 | PETG 10 thick x14 ribs; actual preserve seats/bolt holes; right; 22.2 bearing seats, 20.2 outer-ring shoulders. | 317.021 | 317.021 | nominal solid volume x assumed density
B | P_GUARD_1 | printed | 1 | Per-stage guard31 deep,2back/2.5walls, two chassis-rod tabs, rear-accessible captiveM3 cover nuts; not certified containment. | 174.4821 | 174.4821 | nominal solid volume x assumed density
B | P_GUARD_2 | printed | 1 | Per-stage guard31 deep,2back/2.5walls, two chassis-rod tabs, rear-accessible captiveM3 cover nuts; not certified containment. | 180.4982 | 180.4982 | nominal solid volume x assumed density
B | P_GUARD_3 | printed | 1 | Per-stage guard31 deep,2back/2.5walls, two chassis-rod tabs, rear-accessible captiveM3 cover nuts; not certified containment. | 177.7571 | 177.7571 | nominal solid volume x assumed density
B | P_ROTOR_CORE | printed | 1 | Rotor core/endplate5 thick,14.2pilot,4M4 mounting; opposite end has mirrored hole pattern. | 38.2577 | 38.2577 | nominal solid volume x assumed density
B | P_ROTOR_CORE_R | printed | 1 | Rotor core/endplate5 thick,14.2pilot,4M4 mounting; opposite end has mirrored hole pattern. | 38.2577 | 38.2577 | nominal solid volume x assumed density
B | P_ROTOR_CUP | printed | 2 | Scoop for diameter90, span180, wall2; shaft clearance10; open-access M3 nuts. | 31.9484 | 63.8967 | nominal solid volume x assumed density
B | P_S1_PINION | printed | 1 | Involute20deg,m2.0,z21,8face,pair backlash0.30;4M4 bolted REX hub; phase follows actual stage axis vector. | 11.1141 | 11.1141 | nominal solid volume x assumed density
B | P_S1_WHEEL | printed | 1 | Involute20deg,m2.0,z84,8face,pair backlash0.30;4M4 bolted REX hub; phase follows actual stage axis vector. | 138.7839 | 138.7839 | nominal solid volume x assumed density
B | P_S2_PINION | printed | 1 | Involute20deg,m2.0,z21,8face,pair backlash0.30;4M4 bolted REX hub; phase follows actual stage axis vector. | 11.1141 | 11.1141 | nominal solid volume x assumed density
B | P_S2_WHEEL | printed | 1 | Involute20deg,m2.0,z84,8face,pair backlash0.30;4M4 bolted REX hub; phase follows actual stage axis vector. | 138.7839 | 138.7839 | nominal solid volume x assumed density
B | P_S3_PINION | printed | 1 | Involute20deg,m2.0,z21,8face,pair backlash0.30;4M4 bolted REX hub; phase follows actual stage axis vector. | 11.1141 | 11.1141 | nominal solid volume x assumed density
B | P_S3_WHEEL | printed | 1 | Involute20deg,m2.0,z84,8face,pair backlash0.30;4M4 bolted REX hub; phase follows actual stage axis vector. | 138.7839 | 138.7839 | nominal solid volume x assumed density
B | P_SHOE | printed | 6 | PETG shoe40.0x18.0x5.0, free M3/4mm-bush pitch hinge; replaceable sole; foot dimensions include drivetrain COG/foot-sweep tradeoff. | 5.004 | 30.024 | nominal solid volume x assumed density
B | Q_BEARING_FIT | printed | 0 | Separate21.9/22.1/22.3 bearing seat coupon; assembly quantity0. | 17.9759 | 0.0 | nominal solid volume x assumed density
B | Q_JOINT_FIT | printed | 0 | Separate4.0/4.2/6.0/6.2/8.2 bore coupon; assembly quantity0. | 9.5127 | 0.0 | nominal solid volume x assumed density
B | S_SOLE | cut_to_length | 6 | Rubber/foam sole40.0x18.0x3; two4.2-wide,0.5-deep strap recesses; grip/compliance unmeasured; density0.8 assumed. | 1.6675 | 10.0051 | nominal solid volume x assumed density
B | S_WINDOW_1 | cut_to_length | 1 | Clear PETG sheet1, cut/drill from CAD, fourM3x35,10shaft apertures; not a printed part. | 50.9677 | 50.9677 | nominal solid volume x assumed density
B | S_WINDOW_2 | cut_to_length | 1 | Clear PETG sheet1, cut/drill from CAD, fourM3x35,10shaft apertures; not a printed part. | 55.3027 | 55.3027 | nominal solid volume x assumed density
B | S_WINDOW_3 | cut_to_length | 1 | Clear PETG sheet1, cut/drill from CAD, fourM3x35,10shaft apertures; not a printed part. | 53.1628 | 53.1628 | nominal solid volume x assumed density

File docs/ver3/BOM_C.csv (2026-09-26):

prototype | part_id | category | quantity | specification | nominal_unit_mass_g | nominal_total_mass_g | mass_basis
C | H_608 | purchased | 12 | 608-ZZ 8x22x7; ring/ shield envelopes, assumed12g, verify actual ring faces and starting drag. | 12 | 144 | assumed unit mass
C | H_BODY_TIE | cut_to_length | 2 | Steel M4 threaded rod x284; simplified thread. | 28.0155 | 56.0309 | nominal solid volume x assumed density
C | H_CASE_TIE_LEFT | cut_to_length | 4 | Steel M4 case tie length84; front carrier and guard-tab supports. | 8.2863 | 33.1451 | nominal solid volume x assumed density
C | H_CASE_TIE_RIGHT | cut_to_length | 4 | Steel M4 case tie length84; front carrier and guard-tab supports. | 8.2863 | 33.1451 | nominal solid volume x assumed density
C | H_COLLAR6 | purchased | 4 | Split collar6 ID, envelope16ODx8, M3 clamp; stationary pivot retention. | 9.8606 | 39.4423 | nominal solid volume x assumed density
C | H_COLLAR8 | purchased | 5 | Split collar8 ID, envelope18ODx8, M3 clamp. Axial retention only; procurement and tightening spec pending. | 11.768 | 58.8398 | nominal solid volume x assumed density
C | H_PIVOT_ROD6 | cut_to_length | 2 | Ground steel6 x282, h8 target; verify finish/straightness; supported at84 mm intervals. | 62.5909 | 125.1818 | nominal solid volume x assumed density
C | H_REX_HUB | purchased | 12 | goBILDA1309-0016-4008, REX8/7AF, 32ODx8 plus14pilotx2, 4xM4 on16square. REX corner datum15deg; reversed hub indexed90deg without moving bolt holes. Flexure and supplied clamp screws simplified. | 14 | 168 | catalogue
C | H_SOLE_STRAP | purchased | 12 | Replaceable nylon cable tie, nominal4 wide; two per sole/plate; lock head simplified; mechanical retention, not adhesive. | 0.1166 | 1.3992 | nominal solid volume x assumed density
C | H_bolt_3_10 | purchased | 24 | ISO 4762 M3x10, socket head; simplified thread | 1.0507 | 25.2158 | nominal solid volume x assumed density
C | H_bolt_3_16 | purchased | 8 | ISO 4762 M3x16, socket head; simplified thread | 1.3836 | 11.0687 | nominal solid volume x assumed density
C | H_bolt_3_20 | purchased | 6 | ISO 4762 M3x20, socket head; simplified thread | 1.6055 | 9.6332 | nominal solid volume x assumed density
C | H_bolt_3_25 | purchased | 9 | ISO 4762 M3x25, socket head; simplified thread | 1.883 | 16.9468 | nominal solid volume x assumed density
C | H_bolt_3_30 | purchased | 3 | ISO 4762 M3x30, socket head; simplified thread | 2.1604 | 6.4813 | nominal solid volume x assumed density
C | H_bolt_3_35 | purchased | 14 | ISO 4762 M3x35, socket head; simplified thread | 2.4379 | 34.1301 | nominal solid volume x assumed density
C | H_bolt_3_55 | purchased | 6 | ISO 4762 M3x55, socket head; simplified thread | 3.5476 | 21.2858 | nominal solid volume x assumed density
C | H_bolt_4_12 | purchased | 8 | ISO 4762 M4x12, socket head; simplified thread | 2.2698 | 18.1584 | nominal solid volume x assumed density
C | H_bolt_4_16 | purchased | 24 | ISO 4762 M4x16, socket head; simplified thread | 2.6644 | 63.9451 | nominal solid volume x assumed density
C | H_bolt_4_45 | purchased | 3 | ISO 4762 M4x45, socket head; simplified thread | 5.5251 | 16.5753 | nominal solid volume x assumed density
C | H_button_4_8 | purchased | 12 | ISO 7380-1 M4x8; simplified thread | 1.5259 | 18.3105 | nominal solid volume x assumed density
C | H_countersunk_4_16 | purchased | 24 | ISO 10642 M4x16, 90-degree countersunk, 2.5 mm hex; flush below cheek face; simplified thread | 1.7777 | 42.6638 | nominal solid volume x assumed density
C | H_crank_sleeve_4_3p2 | cut_to_length | 12 | Cut brass tube 4.2 ID x 6 OD x 3.2; crank journal/spacer | 0.3922 | 4.7067 | nominal solid volume x assumed density
C | H_crank_sleeve_4_4p7 | cut_to_length | 3 | Cut brass tube 4.2 ID x 6 OD x 4.7; crank journal/spacer | 0.5761 | 1.7282 | nominal solid volume x assumed density
C | H_endwasher_4 | purchased | 12 | Steel end-stop washer 4.2 ID x 12 OD x 0.8; positive shaft retention | 0.6232 | 7.4789 | nominal solid volume x assumed density
C | H_inner_spacer_3_1p7 | cut_to_length | 3 | Steel spacer/shim 8.1 ID x 10 OD x 1.7; INNER RING ONLY | 0.3604 | 1.0813 | nominal solid volume x assumed density
C | H_inner_spacer_3_2p6 | cut_to_length | 2 | Steel spacer/shim 8.1 ID x 10 OD x 2.6; INNER RING ONLY | 0.5513 | 1.1025 | nominal solid volume x assumed density
C | H_inner_spacer_3_3p1 | cut_to_length | 1 | Steel spacer/shim 8.1 ID x 10 OD x 3.1; INNER RING ONLY | 0.6573 | 0.6573 | nominal solid volume x assumed density
C | H_locknut_3 | purchased | 30 | ISO 10511 prevailing-torque M3 nut; simplified thread | 0.6006 | 18.0192 | nominal solid volume x assumed density
C | H_locknut_4 | purchased | 23 | ISO 10511 prevailing-torque M4 nut; simplified thread | 1.1724 | 26.9641 | nominal solid volume x assumed density
C | H_nut_3 | purchased | 40 | ISO 4032 M3 nut; simplified thread | 0.3604 | 14.4154 | nominal solid volume x assumed density
C | H_nut_4 | purchased | 8 | ISO 4032 M4 nut; simplified thread | 0.7503 | 6.0024 | nominal solid volume x assumed density
C | H_pivot_sleeve_3_3p2 | cut_to_length | 12 | Cut brass sleeve 6.1 ID x 8 OD x 3.2; stationary pivot journal | 0.5723 | 6.8677 | nominal solid volume x assumed density
C | H_pivot_sleeve_3_4p7 | cut_to_length | 3 | Cut brass sleeve 6.1 ID x 8 OD x 4.7; stationary pivot journal | 0.8406 | 2.5217 | nominal solid volume x assumed density
C | H_pivot_sleeve_3_4p8 | cut_to_length | 6 | Cut brass sleeve 6.1 ID x 8 OD x 4.8; stationary pivot journal | 0.8585 | 5.1508 | nominal solid volume x assumed density
C | H_pivot_sleeve_3_55p7 | cut_to_length | 3 | Cut brass sleeve 6.1 ID x 8 OD x 55.7; stationary pivot journal | 9.9618 | 29.8853 | nominal solid volume x assumed density
C | H_pivot_sleeve_3_59p7 | cut_to_length | 3 | Cut brass sleeve 6.1 ID x 8 OD x 59.7; stationary pivot journal | 10.6772 | 32.0315 | nominal solid volume x assumed density
C | H_pivot_sleeve_3_8p7 | cut_to_length | 3 | Cut brass sleeve 6.1 ID x 8 OD x 8.7; stationary pivot journal | 1.556 | 4.6679 | nominal solid volume x assumed density
C | H_shaft_8_111p5 | cut_to_length | 1 | 8 mm REX, 7 mm AF, corner datum15deg, cut to 111.5; M4x10 axial tapped holes both ends; machining/procurement verification pending | 35.7839 | 35.7839 | nominal solid volume x assumed density
C | H_shaft_8_344 | cut_to_length | 1 | 8 mm REX, 7 mm AF, corner datum15deg, cut to 344; M4x10 axial tapped holes both ends; machining/procurement verification pending | 113.2006 | 113.2006 | nominal solid volume x assumed density
C | H_shaft_8_37p5 | cut_to_length | 1 | 8 mm REX, 7 mm AF, corner datum15deg, cut to 37.5; M4x10 axial tapped holes both ends; machining/procurement verification pending | 11.1437 | 11.1437 | nominal solid volume x assumed density
C | H_shaft_8_396 | cut_to_length | 1 | 8 mm REX, 7 mm AF, corner datum15deg, cut to 396; M4x10 axial tapped holes both ends; machining/procurement verification pending | 130.5153 | 130.5153 | nominal solid volume x assumed density
C | H_shaft_8_57 | cut_to_length | 2 | 8 mm REX, 7 mm AF, corner datum15deg, cut to 57; M4x10 axial tapped holes both ends; machining/procurement verification pending | 17.6368 | 35.2735 | nominal solid volume x assumed density
C | H_sleeve_3_10 | cut_to_length | 3 | Cut brass tube 3.2 ID x 4 OD x 10, deburred; bearing journal/rigid clamp stack | 0.3845 | 1.1536 | nominal solid volume x assumed density
C | H_sleeve_3_12p3 | cut_to_length | 3 | Cut brass tube 3.2 ID x 4 OD x 12.3, deburred; bearing journal/rigid clamp stack | 0.473 | 1.4189 | nominal solid volume x assumed density
C | H_sleeve_3_37p3 | cut_to_length | 6 | Cut brass tube 3.2 ID x 4 OD x 37.3, deburred; bearing journal/rigid clamp stack | 1.4343 | 8.6058 | nominal solid volume x assumed density
C | H_sleeve_3_3p2 | cut_to_length | 60 | Cut brass tube 3.2 ID x 4 OD x 3.2, deburred; bearing journal/rigid clamp stack | 0.123 | 7.383 | nominal solid volume x assumed density
C | H_sleeve_3_4p6 | cut_to_length | 3 | Cut brass tube 3.2 ID x 4 OD x 4.6, deburred; bearing journal/rigid clamp stack | 0.1769 | 0.5307 | nominal solid volume x assumed density
C | H_sleeve_3_6p6 | cut_to_length | 3 | Cut brass tube 3.2 ID x 4 OD x 6.6, deburred; bearing journal/rigid clamp stack | 0.2538 | 0.7614 | nominal solid volume x assumed density
C | H_sleeve_3_7p3 | cut_to_length | 6 | Cut brass tube 3.2 ID x 4 OD x 7.3, deburred; bearing journal/rigid clamp stack | 0.2807 | 1.6842 | nominal solid volume x assumed density
C | H_sleeve_3_8 | cut_to_length | 3 | Cut brass tube 3.2 ID x 4 OD x 8, deburred; bearing journal/rigid clamp stack | 0.3076 | 0.9229 | nominal solid volume x assumed density
C | H_sleeve_3_8p9 | cut_to_length | 3 | Cut brass tube 3.2 ID x 4 OD x 8.9, deburred; bearing journal/rigid clamp stack | 0.3422 | 1.0267 | nominal solid volume x assumed density
C | H_tie_tube_3_36 | cut_to_length | 4 | Cut aluminium tube 6 ID x 10 OD x 36; square ends | 4.8858 | 19.5432 | nominal solid volume x assumed density
C | H_tie_tube_3_44 | cut_to_length | 4 | Cut aluminium tube 6 ID x 10 OD x 44; square ends | 5.9715 | 23.8862 | nominal solid volume x assumed density
C | H_tie_tube_3_6 | cut_to_length | 4 | Cut aluminium tube 6 ID x 10 OD x 6; square ends | 0.8143 | 3.2572 | nominal solid volume x assumed density
C | H_tie_tube_3_76 | cut_to_length | 6 | Cut aluminium tube 6 ID x 10 OD x 76; square ends | 10.3145 | 61.8869 | nominal solid volume x assumed density
C | H_washer_3_0p5 | purchased | 118 | Washer 3.2 ID x 7 OD x 0.5; verify purchased thickness | 0.1195 | 14.0992 | nominal solid volume x assumed density
C | H_washer_4_0p5 | purchased | 15 | Washer 4.2 ID x 9 OD x 0.5; verify purchased thickness | 0.1953 | 2.9298 | nominal solid volume x assumed density
C | H_washer_4_0p8 | purchased | 58 | Washer 4.2 ID x 9 OD x 0.8; verify purchased thickness | 0.3125 | 18.1256 | nominal solid volume x assumed density
C | L_AB | printed | 6 | PETG Jansen L_AB; thickness3, web8; P bore8.2, A bore6.2, other joints4.2; mirrored triangles have_R suffix. | 2.1741 | 13.0448 | nominal solid volume x assumed density
C | L_AC | printed | 6 | PETG Jansen L_AC; thickness3, web7.5; P bore8.2, A bore6.2, other joints4.2; mirrored triangles have_R suffix. | 2.5164 | 15.0982 | nominal solid volume x assumed density
C | L_CEF | printed | 3 | PETG Jansen L_CEF; thickness3, web8; P bore8.2, A bore6.2, other joints4.2; mirrored triangles have_R suffix. | 5.9561 | 17.8684 | nominal solid volume x assumed density
C | L_CEF_R | printed | 3 | PETG Jansen L_CEF_R; thickness3, web8; P bore8.2, A bore6.2, other joints4.2; mirrored triangles have_R suffix. | 5.9561 | 17.8684 | nominal solid volume x assumed density
C | L_DE | printed | 6 | PETG Jansen L_DE; thickness3, web8; P bore8.2, A bore6.2, other joints4.2; mirrored triangles have_R suffix. | 1.7255 | 10.3528 | nominal solid volume x assumed density
C | L_PBD | printed | 3 | PETG Jansen L_PBD; thickness3, web8; P bore8.2, A bore6.2, other joints4.2; mirrored triangles have_R suffix. | 5.4686 | 16.4057 | nominal solid volume x assumed density
C | L_PBD_R | printed | 3 | PETG Jansen L_PBD_R; thickness3, web8; P bore8.2, A bore6.2, other joints4.2; mirrored triangles have_R suffix. | 5.4686 | 16.4057 | nominal solid volume x assumed density
C | L_PC | printed | 6 | PETG Jansen L_PC; thickness3, web8; P bore8.2, A bore6.2, other joints4.2; mirrored triangles have_R suffix. | 1.8592 | 11.1552 | nominal solid volume x assumed density
C | P_BEARING_RETAINER | printed | 12 | 44ODx2,20.2aperture,twoM3 on32PCD; outer ring only. | 2.9337 | 35.2046 | nominal solid volume x assumed density
C | P_CRANK_CHEEK | printed | 6 | 8 thick, crank21; metal flange4M4x16 countersunk; recessed M4 shaft end stops; M4 shared crank pin. | 8.7269 | 52.3613 | nominal solid volume x assumed density
C | P_FRAME_CORE | printed | 2 | PETG 8 thick x8 ribs; actual preserve seats/bolt holes; core; 22.2 bearing seats, 20.2 outer-ring shoulders. | 46.9073 | 93.8146 | nominal solid volume x assumed density
C | P_FRAME_FRONT_LEFT | printed | 1 | PETG 8 thick x8 ribs; actual preserve seats/bolt holes; front_left; 22.2 bearing seats, 20.2 outer-ring shoulders. | 86.9791 | 86.9791 | nominal solid volume x assumed density
C | P_FRAME_FRONT_RIGHT | printed | 1 | PETG 8 thick x8 ribs; actual preserve seats/bolt holes; front_right; 22.2 bearing seats, 20.2 outer-ring shoulders. | 87.8702 | 87.8702 | nominal solid volume x assumed density
C | P_FRAME_LEFT | printed | 1 | PETG 8 thick x8 ribs; actual preserve seats/bolt holes; left; 22.2 bearing seats, 20.2 outer-ring shoulders. | 159.6561 | 159.6561 | nominal solid volume x assumed density
C | P_FRAME_RIGHT | printed | 1 | PETG 8 thick x8 ribs; actual preserve seats/bolt holes; right; 22.2 bearing seats, 20.2 outer-ring shoulders. | 150.1943 | 150.1943 | nominal solid volume x assumed density
C | P_GUARD_1 | printed | 1 | Per-stage guard31 deep,2back/2.5walls, two chassis-rod tabs, rear-accessible captiveM3 cover nuts; not certified containment. | 178.421 | 178.421 | nominal solid volume x assumed density
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

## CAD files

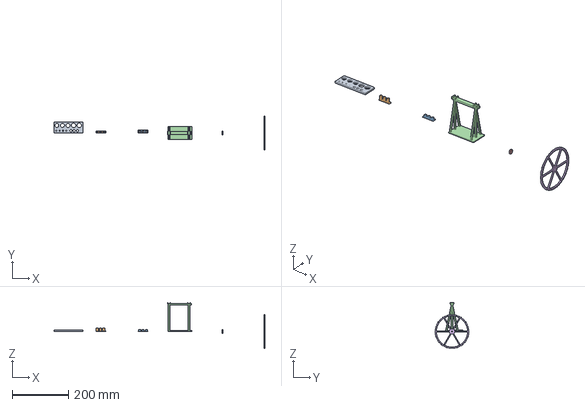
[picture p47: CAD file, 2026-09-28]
FreeCAD/Ver.3/integrated_r7/common/AssemblyAccessories.step
753.2 x 121.9 x 164.9 mm

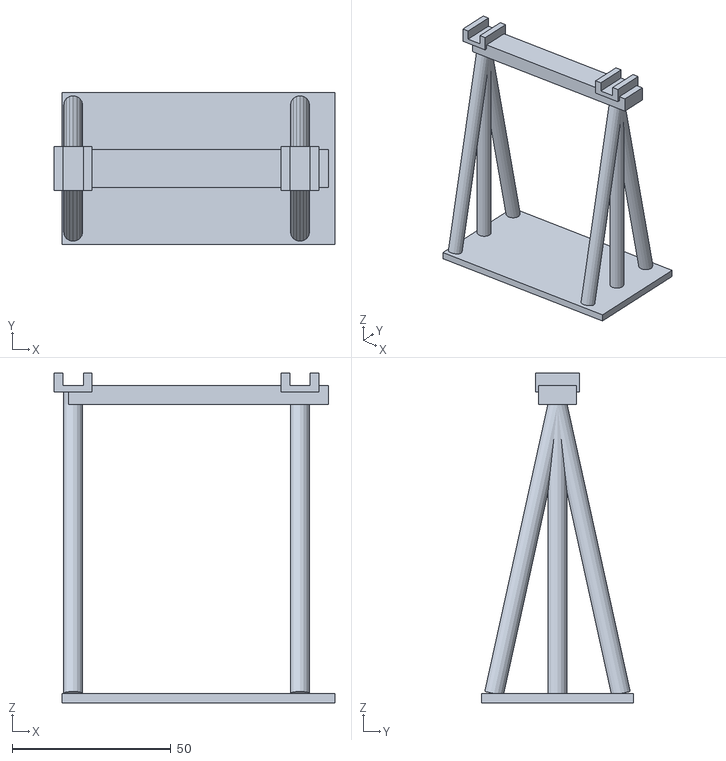
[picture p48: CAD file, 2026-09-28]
STL/Ver.3/integrated_r7/common/T_ASSEMBLY_CRADLE.stl
88.5 x 48.0 x 104.0

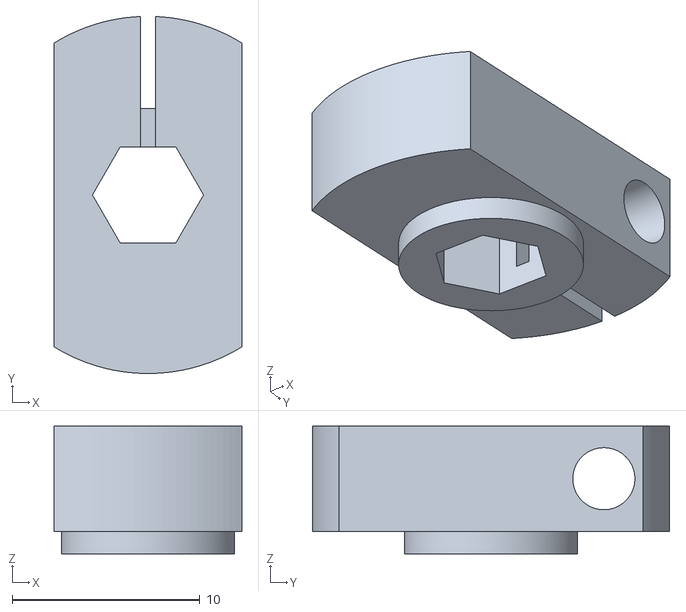
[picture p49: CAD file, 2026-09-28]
STL/Ver.3/integrated_r7/A/P_MAIN_INNER_STOP.stl
10.0 x 19.0 x 6.80

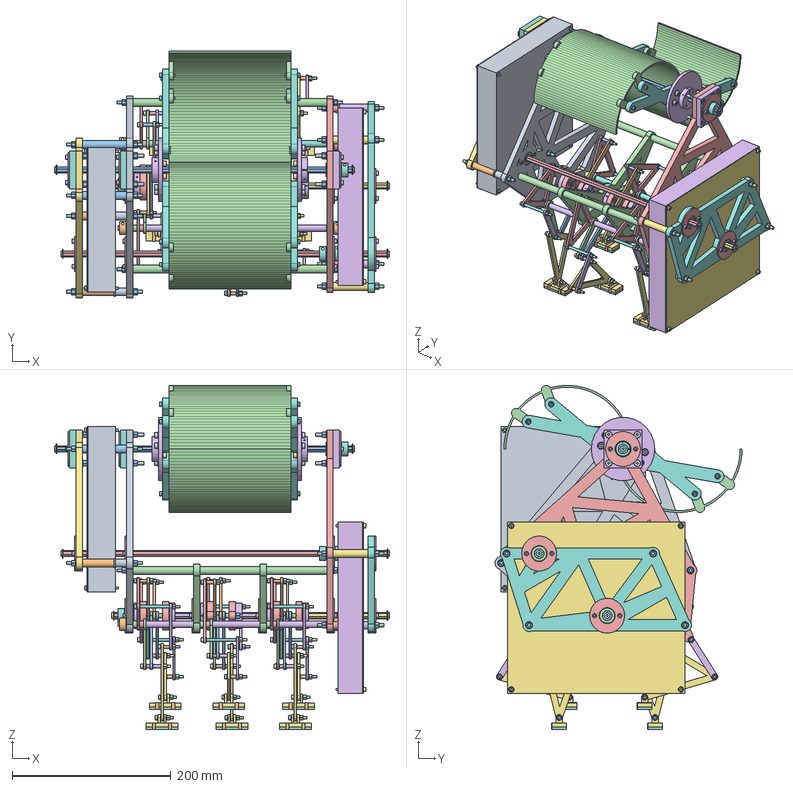
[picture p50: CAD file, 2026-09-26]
FreeCAD/Ver.3/A/Ver3_A.step
422.0 x 311.4 x 433.5 mm

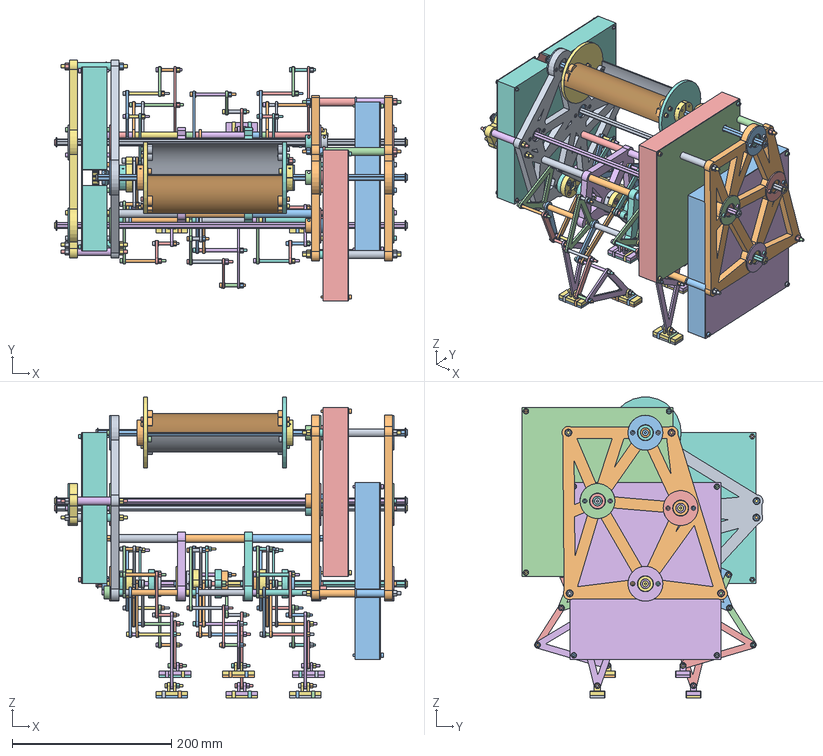
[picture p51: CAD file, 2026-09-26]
FreeCAD/Ver.3/B/Ver3_B.FCStd
444.0 x 303.2 x 378.1 mm
P_FRAME_LEFT_001
P_BEARING_RETAINER_001
P_BEARING_RETAINER_002
P_BEARING_RETAINER_003
P_BEARING_RETAINER_004
P_FRAME_CORE_001
P_BEARING_RETAINER_005
P_FRAME_CORE_002
P_BEARING_RETAINER_006
P_FRAME_RIGHT_001
P_BEARING_RETAINER_007
P_BEARING_RETAINER_008
P_BEARING_RETAINER_009
P_BEARING_RETAINER_010
P_FRAME_FRONT_LEFT_001
P_BEARING_RETAINER_011
P_BEARING_RETAINER_012
P_FRAME_FRONT_RIGHT_001
P_BEARING_RETAINER_013
P_BEARING_RETAINER_014
P_BEARING_RETAINER_015
P_BEARING_RETAINER_016
P_CRANK_CHEEK_001
P_CRANK_CHEEK_002
L_AB_001
L_AC_001
L_PC_001
L_PBD_001
L_DE_001
L_CEF_001
P_SHOE_001
L_AB_002
L_AC_002
L_PC_002
L_PBD_R_001
L_DE_002
L_CEF_R_001
P_SHOE_002
P_CRANK_CHEEK_003
P_CRANK_CHEEK_004
L_AB_003
L_AC_003
L_PC_003
L_PBD_002
L_DE_003
L_CEF_002
P_SHOE_003
L_AB_004
L_AC_004
L_PC_004
L_PBD_R_002
L_DE_004
L_CEF_R_002
P_SHOE_004
P_CRANK_CHEEK_005
P_CRANK_CHEEK_006
L_AB_005
L_AC_005
L_PC_005
L_PBD_003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

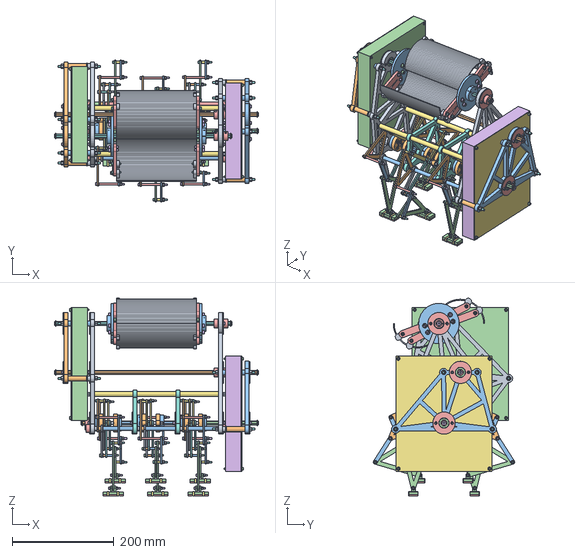
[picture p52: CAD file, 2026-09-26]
FreeCAD/Ver.3/C/Ver3_C.step
402.0 x 278.9 x 389.6 mm

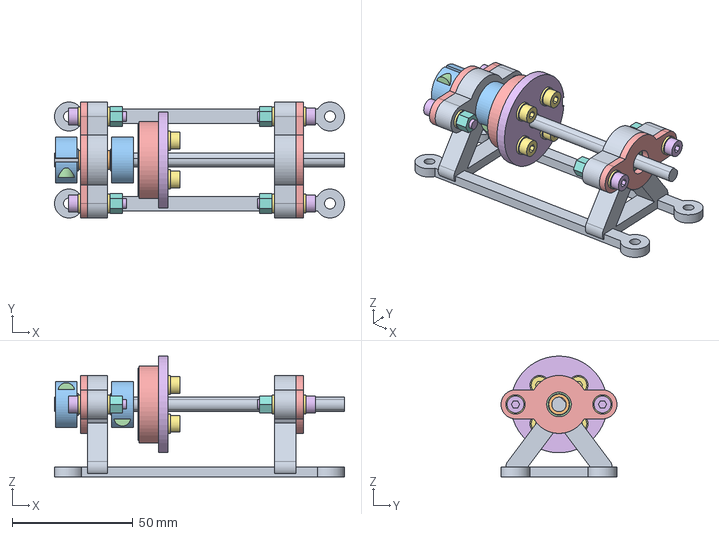
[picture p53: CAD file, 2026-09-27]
FreeCAD/Ver.3/common_input_r4/CommonInputR4.step
120.0 x 48.0 x 50.0 mm

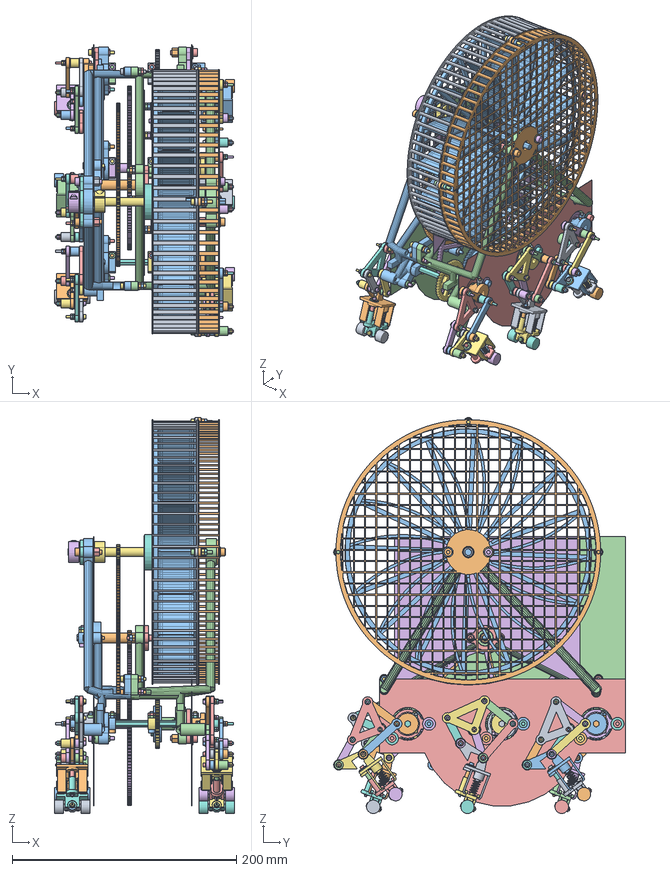
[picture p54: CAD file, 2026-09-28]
FreeCAD/Ver.3/integrated_r7/A/Walker_A.FCStd
160.8 x 260.0 x 353.0 mm
P_CRANK_JOURNAL__1_0_001
P_CRANK_JOURNAL_1_180_001
P_MAIN_INNER_STOP_001
CAP_MAIN_L__84_0
CAP_MAIN_R__84_0
P_CRANK_JOURNAL__1_180_001
P_CRANK_JOURNAL_1_0_001
CAP_MAIN_L_0_0
CAP_MAIN_R_0_0
P_CRANK_JOURNAL__1_0_002
P_CRANK_JOURNAL_1_180_002
P_MAIN_INNER_STOP_002
CAP_MAIN_L_84_0
CAP_MAIN_R_84_0
P_SYNC_DRIVE_001
P_IDLER_CAP_001
P_IDLER_JOURNAL_001
P_IDLER_INNER_WASHER_001
P_SYNC_IDLER_001
P_SYNC_DRIVE_002
P_IDLER_CAP_002
P_IDLER_JOURNAL_002
P_IDLER_INNER_WASHER_002
P_SYNC_IDLER_002
P_SYNC_DRIVE_003
P_COMPOUND_1_001
P_INTER_STOP_001
CAP_INTER_L_1
CAP_INTER_R_1
P_OUTPUT_WHEEL_001
P_INPUT_PINION_001
CAP_INPUT_FIXED
P_ROTOR_CAGE_FRONT_001
CAP_INPUT_FLOAT
CHASSIS_L
CHASSIS_R
P_LEG_AB_L_001
P_LEG_AC_L_001
P_LEG_PC_L_001
P_LEG_PBD_L_001
P_LEG_DE_L_001
P_LEG_CEF_L_001
P_LAYER_SPACER_7_4_001
P_LAYER_SPACER_3_3_001
P_PIN_TAIL_4_3_001
P_LAYER_SPACER_3_3_002
P_PIN_TAIL_8_4_001
P_FOOT_SLIDER_L_001
P_FOOT_ROCKER_L_001
P_LEG_AB_R_001
P_LEG_AC_R_001
P_LEG_PC_R_001
P_LEG_PBD_R_001
P_LEG_DE_R_001
P_LEG_CEF_R_001
P_LAYER_SPACER_7_4_002
P_LAYER_SPACER_3_3_003
P_PIN_TAIL_4_3_002
P_LAYER_SPACER_3_3_004
P_PIN_TAIL_8_4_002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

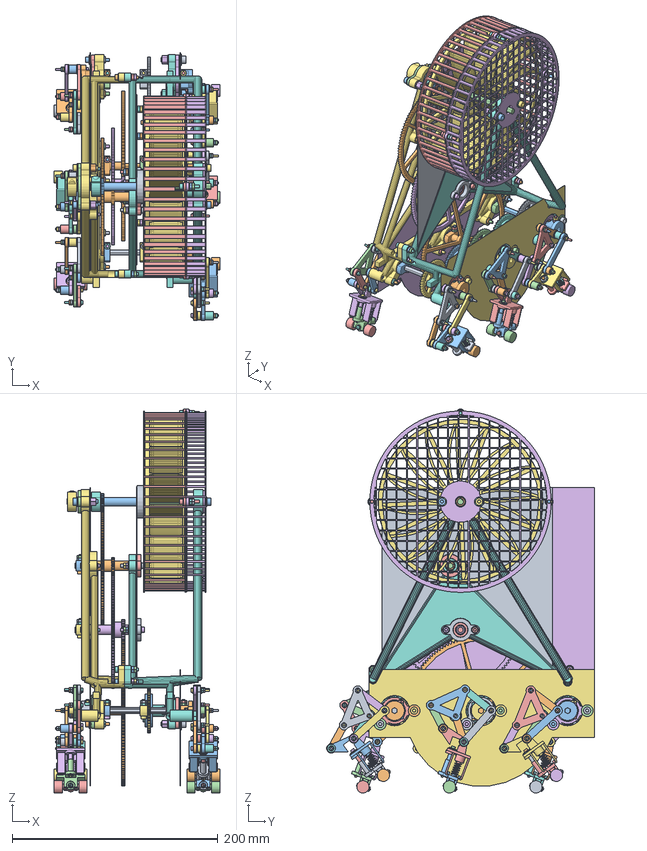
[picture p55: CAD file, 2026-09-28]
FreeCAD/Ver.3/integrated_r7/B/Walker_B.FCStd
160.8 x 260.0 x 372.8 mm
P_CRANK_JOURNAL__1_0_001
P_CRANK_JOURNAL_1_180_001
P_MAIN_INNER_STOP_001
CAP_MAIN_L__84_0
CAP_MAIN_R__84_0
P_CRANK_JOURNAL__1_180_001
P_CRANK_JOURNAL_1_0_001
CAP_MAIN_L_0_0
CAP_MAIN_R_0_0
P_CRANK_JOURNAL__1_0_002
P_CRANK_JOURNAL_1_180_002
P_MAIN_INNER_STOP_002
CAP_MAIN_L_84_0
CAP_MAIN_R_84_0
P_SYNC_DRIVE_001
P_IDLER_CAP_001
P_IDLER_JOURNAL_001
P_IDLER_INNER_WASHER_001
P_SYNC_IDLER_001
P_SYNC_DRIVE_002
P_IDLER_CAP_002
P_IDLER_JOURNAL_002
P_IDLER_INNER_WASHER_002
P_SYNC_IDLER_002
P_SYNC_DRIVE_003
P_COMPOUND_1_001
P_INTER_STOP_001
CAP_INTER_L_1
CAP_INTER_R_1
P_COMPOUND_2_001
P_INTER_STOP_002
CAP_INTER_L_2
CAP_INTER_R_2
P_OUTPUT_WHEEL_001
P_INPUT_PINION_001
CAP_INPUT_FIXED
P_ROTOR_CAGE_FRONT_001
CAP_INPUT_FLOAT
CHASSIS_L
CHASSIS_R
P_LEG_AB_L_001
P_LEG_AC_L_001
P_LEG_PC_L_001
P_LEG_PBD_L_001
P_LEG_DE_L_001
P_LEG_CEF_L_001
P_LAYER_SPACER_7_4_001
P_LAYER_SPACER_3_3_001
P_PIN_TAIL_4_3_001
P_LAYER_SPACER_3_3_002
P_PIN_TAIL_8_4_001
P_FOOT_SLIDER_L_001
P_FOOT_ROCKER_L_001
P_LEG_AB_R_001
P_LEG_AC_R_001
P_LEG_PC_R_001
P_LEG_PBD_R_001
P_LEG_DE_R_001
P_LEG_CEF_R_001
P_LAYER_SPACER_7_4_002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

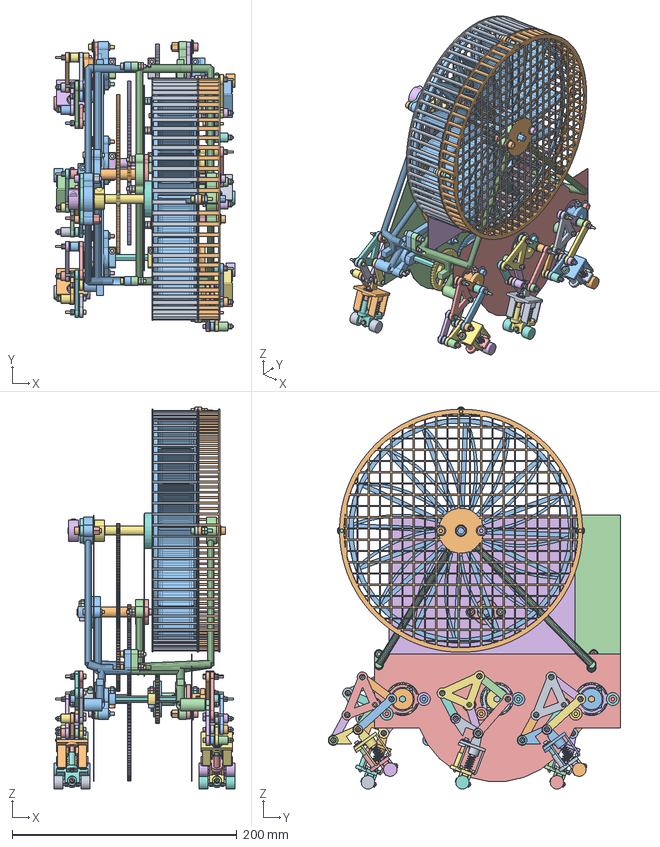
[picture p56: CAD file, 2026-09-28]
FreeCAD/Ver.3/integrated_r7/C/Walker_C.FCStd
160.8 x 260.0 x 339.6 mm
P_CRANK_JOURNAL__1_0_001
P_CRANK_JOURNAL_1_180_001
P_MAIN_INNER_STOP_001
CAP_MAIN_L__84_0
CAP_MAIN_R__84_0
P_CRANK_JOURNAL__1_180_001
P_CRANK_JOURNAL_1_0_001
CAP_MAIN_L_0_0
CAP_MAIN_R_0_0
P_CRANK_JOURNAL__1_0_002
P_CRANK_JOURNAL_1_180_002
P_MAIN_INNER_STOP_002
CAP_MAIN_L_84_0
CAP_MAIN_R_84_0
P_SYNC_DRIVE_001
P_IDLER_CAP_001
P_IDLER_JOURNAL_001
P_IDLER_INNER_WASHER_001
P_SYNC_IDLER_001
P_SYNC_DRIVE_002
P_IDLER_CAP_002
P_IDLER_JOURNAL_002
P_IDLER_INNER_WASHER_002
P_SYNC_IDLER_002
P_SYNC_DRIVE_003
P_COMPOUND_1_001
P_INTER_STOP_001
CAP_INTER_L_1
CAP_INTER_R_1
P_OUTPUT_WHEEL_001
P_INPUT_PINION_001
CAP_INPUT_FIXED
P_ROTOR_CAGE_FRONT_001
CAP_INPUT_FLOAT
CHASSIS_L
CHASSIS_R
P_LEG_AB_L_001
P_LEG_AC_L_001
P_LEG_PC_L_001
P_LEG_PBD_L_001
P_LEG_DE_L_001
P_LEG_CEF_L_001
P_LAYER_SPACER_7_4_001
P_LAYER_SPACER_3_3_001
P_PIN_TAIL_4_3_001
P_LAYER_SPACER_3_3_002
P_PIN_TAIL_8_4_001
P_FOOT_SLIDER_L_001
P_FOOT_ROCKER_L_001
P_LEG_AB_R_001
P_LEG_AC_R_001
P_LEG_PC_R_001
P_LEG_PBD_R_001
P_LEG_DE_R_001
P_LEG_CEF_R_001
P_LAYER_SPACER_7_4_002
P_LAYER_SPACER_3_3_003
P_PIN_TAIL_4_3_002
P_LAYER_SPACER_3_3_004
P_PIN_TAIL_8_4_002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

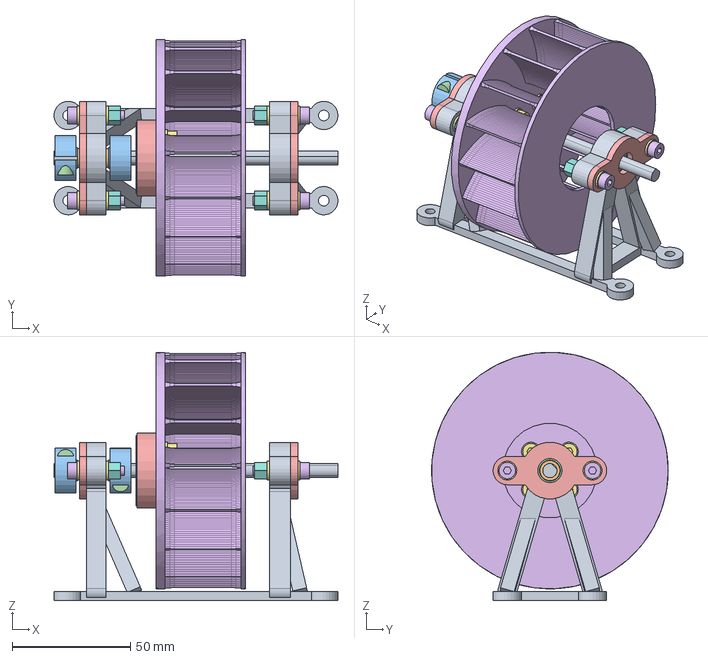
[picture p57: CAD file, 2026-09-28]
FreeCAD/Ver.3/wind_module_r6/WindModuleR6.step
120.0 x 99.9 x 105.0 mm

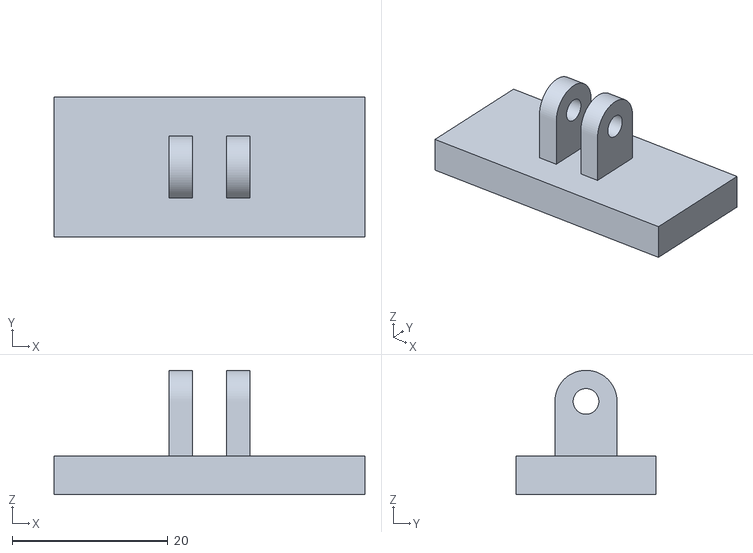
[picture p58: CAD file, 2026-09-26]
STL/Ver.3/A/P_SHOE.stl
40.0 x 18.0 x 16.0

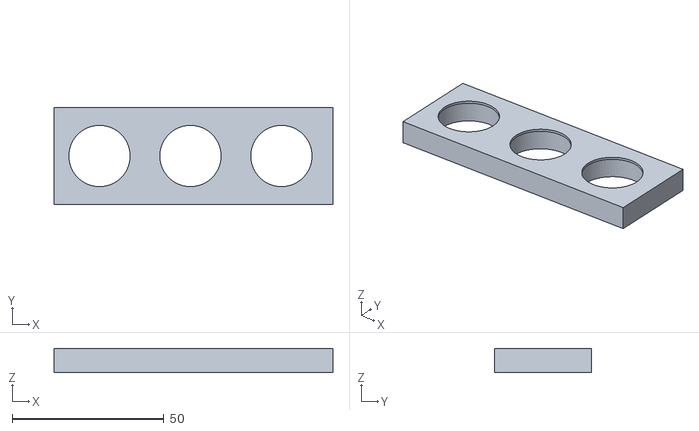
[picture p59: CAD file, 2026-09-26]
STL/Ver.3/B/Q_BEARING_FIT.stl
92.0 x 32.0 x 8.00

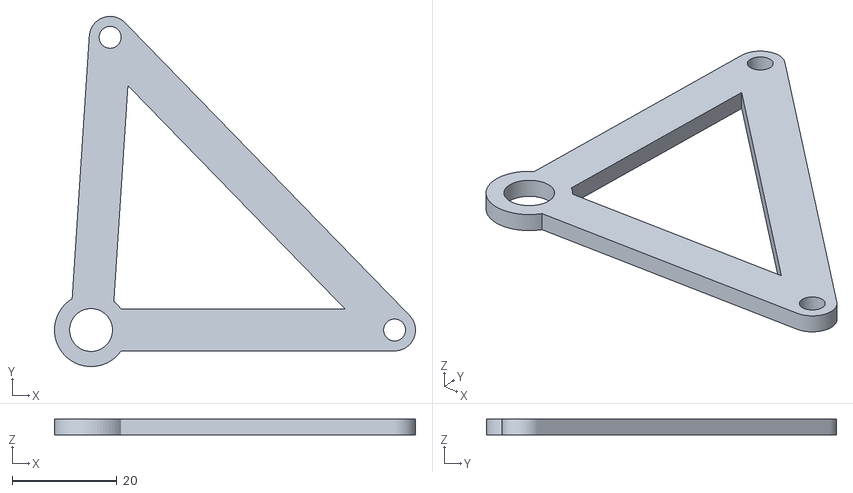
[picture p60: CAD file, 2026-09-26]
STL/Ver.3/C/L_PBD.stl
69.1 x 67.0 x 3.00

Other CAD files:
STL/Ver.3/integrated_r7/A/P_FOOT_SLIDER_R.stl
STL/Ver.3/integrated_r7/B/P_FOOT_SLIDER_R.stl
FreeCAD/Ver.3/A/Ver3_A.FCStd
FreeCAD/Ver.3/C/Ver3_C.FCStd
FreeCAD/Ver.3/common_input_r4/CommonInputR4.FCStd
FreeCAD/Ver.3/integrated_r7/common/AssemblyAccessories.FCStd
FreeCAD/Ver.3/wind_module_r6/WindModuleR6.FCStd
STL/Ver.1/Spur Gear (19 teeth).stl
STL/Ver.1/Spur Gear (5 teeth).stl
STL/Ver.1/Spur Gear (8 teeth) (1).stl
STL/Ver.1/Spur Gear (8 teeth) (2).stl
STL/Ver.1/Spur Gear (9 teeth).stl
STL/Ver.1/body.7.4.stl
STL/Ver.1/body1.1.stl
STL/Ver.1/body1.2.stl
STL/Ver.1/body1.3.stl
STL/Ver.1/body1.4.stl
STL/Ver.1/body1.5.stl
STL/Ver.1/body1.6.stl
STL/Ver.1/body1.7.stl
STL/Ver.1/body1.8.stl
STL/Ver.1/body10.1.stl
STL/Ver.1/body10.2.stl
STL/Ver.1/body10.3.stl
STL/Ver.1/body10.4.stl
STL/Ver.1/body10.5.stl
STL/Ver.1/body10.6.stl
STL/Ver.1/body10.7.stl
STL/Ver.1/body10.8.stl
STL/Ver.1/body11.1.stl
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

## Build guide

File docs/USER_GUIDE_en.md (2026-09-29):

# Using the website and documents

[日本語](USER_GUIDE_ja.md) | [English](USER_GUIDE_en.md) | [Document language pairs](README_en.md)

## Choose the right page

The [Japanese site](https://ktanino10.github.io/TeoJansen_Rhinoceros/) retains the existing URLs. [English](https://ktanino10.github.io/TeoJansen_Rhinoceros/en/) provides equivalent content. Each page's language switch preserves the page, design query and heading anchor. Language selection uses no account, remote preference storage or analytics.

| Page | Content and revision |
|---|---|
| [Overview](https://ktanino10.github.io/TeoJansen_Rhinoceros/en/index.html) | Current Ver.3.1 images, values and downloads first; Ver.1/2/3.0 history is separate |
| [Build records](https://ktanino10.github.io/TeoJansen_Rhinoceros/en/production.html) | Ver.1 fabrication and the recorded Ver.2 improvements, completed photographs and historical tests |
| [Ver.3.0 initial concepts / archive](https://ktanino10.github.io/TeoJansen_Rhinoceros/en/comparison.html) | Historical A300/B90/C180 mm matrix, CG, prescribed videos and old downloads |
| [Ver.3.0 archived 360° and assembly](https://ktanino10.github.io/TeoJansen_Rhinoceros/en/viewer.html) | Exact meshes, part IDs and source-bound stages of the old revision, not the current design |
| [Calculations](https://ktanino10.github.io/TeoJansen_Rhinoceros/en/calculations.html) | Separate r3 materials/structures/fluid models and r4 input cartridge |
| [Ver.3.1 comparison, 360° and 12 stages](https://ktanino10.github.io/TeoJansen_Rhinoceros/en/r7.html) | Current floor-corrected A750/B785/C750 = 2,285 parts; engineering ID r7/floor2 |
| [Ver.3.1 continuous walking](https://ktanino10.github.io/TeoJansen_Rhinoceros/en/walking.html) | Separately versioned kinematic/quasi-static display model and bilingual videos using the same current geometry |

Ver.3.1 is the public name of the existing floor-corrected design, not a change to engineering originals. The [source contract](../site/r7-source.json) retains `v3-integrated-walkers-r7-16-floor2` and the artifact/source commits and hashes. Existing r7 media labels refer to this geometry. `r7-floor2-walking-kinematic-v1` is a separate pose extension on the same geometry. Internal r2/r3/r4/r6 research and subassembly IDs are not public Ver.2 or Ver.3.1.

Old `index.html#ver3` bookmarks now lead to Ver.3.1. `comparison.html` and `viewer.html` retain Ver.3.0 history with clear current-design links. Do not mix [current downloads](https://ktanino10.github.io/TeoJansen_Rhinoceros/en/index.html#downloads) with [archived downloads](https://ktanino10.github.io/TeoJansen_Rhinoceros/en/comparison.html#downloads).

## Operate 3D and videos

The 3D engine, GLB and motion data load only after choosing a design and pressing Load. Walking starts paused. Drag/one finger rotates; wheel/two fingers zoom and pan. Focus the 3D area: arrows rotate, +/− zoom and Home fits all. Assembly also supports Shift+arrows to pan; walking supports Space to play/pause. Instructions appear beside each viewer.

“Complete” assembly is an on-screen reference, not completed physical work. In r7, “Operation boundary / path sample” traces inventories, temporary removal and same-ID reinsertion. Separate-workbench preparation does not add to installed machine quantities. Static instructions, parts tables, images and documents remain available without JavaScript or WebGL.

Videos do not autoplay. Japanese walking pages use Japanese on-screen notes; English pages use English notes. Walking CC is optional rather than duplicated by default. A user's enabled CC is not repeatedly forced off. On small screens, use fullscreen, optional captions and the normal-sized explanatory text beside the video. No blanket shrinking CSS reduces caption readability.

All walking videos use **prescribed 120 rpm input, 16× time compression and 4 cycles**. A about 18 s/B about 64 s/C about 20 s and about 37 cm advance are calculated displays, not measured distance or actual walking performance. Airborne-rocker neutral return and procedural springs are declared display assumptions; canonical independent rocker angles remain null.

[Bilingual media provenance](ver3/r7_walking_locales_v1/manifest.json) records language-specific notes, posters and captions from the same motion and timing. The original model document and its first-release media/delivery-budget statements remain frozen historical records, separate from the current bilingual presentation.

## Document and fabrication-file legend

The 18 major English documents translate unchanged Japanese originals. Each English header links to the original and records its SHA256. The [coverage manifest](translation-manifest.json) records scope and hashes. The existing bilingual repository READMEs preserve Ver.1/2 build records.

- **CAD, STEP, STL and GLB:** shared across languages. No language-driven redesign, remodeling or omitted parts.
- **Seven BOMs and numerical JSON/CSV:** BOM fields are already English/neutral, so original bytes are shared. Quantities, part IDs, SKUs, prices and URLs are unchanged. JSON source annotations may be Japanese; paired major documents provide English explanations.
- **Ver.1 PDF drawings:** [assembly reference](テオヤンセン2Dv1.pdf) / [detail reference](テオヤンセン2D図面最新.pdf) remain **Original drawing (Japanese)**. They are neither translated English drawings nor Ver.2-specific drawings. Missing dimensions, tolerances and operations are not reconstructed from photos.
- **r7 PET templates and sections:** original part IDs and dimensions are shared. Match design, revision and part ID; use the stated mm dimensions. Translation does not change outlines, holes or dimensions. Design-specific and common assembly documents explain cutting and tool conditions.
- **Photos and historical videos:** physical photographs remain distinct from renderings. External YouTube videos retain their original language and are not reuploaded. Existing r7 assembly movies have English burned-in labels, with corresponding Japanese or English stage captions on each page.

Do not apply historical Ver.1/2 scaling of 150% / legs 160% to Ver.3, which uses mm at 100%. Representative slicing is limited software inspection, not qualification of whole-machine printing, support removal or fit. No printer transmission or print start is performed.

## Distinguish status and cost

Current Ver.3.1 (engineering r7/floor2) materials guideline: **about JPY 24,000 per machine**. Individual initial estimates A JPY 23,305.13/B JPY 23,735.37/C JPY 23,154.43 exclude unowned tools such as DN-03 at about JPY 396, shipping and unresolved taxes. Shared-purchase averages do not replace individual costs. Old JPY 20,000/23,000 conditions remain historical to their respective revisions.

`manufacturingRelease=false`, physically qualified count 0, and real wind, physical self-starting and physical 30 cm walking remain UNKNOWN. Finite digital PASS does not qualify every continuous path, tolerance, CFD/FEM, endurance or physical operation. Follow actual product/material, bonding/curing and tool instructions; historical records alone do not guarantee safety.

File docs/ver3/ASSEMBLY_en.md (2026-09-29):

# Ver.3 — Assembly, installation paths and bench checks

[日本語 (original)](ASSEMBLY_ja.md) | **English** | [Document languages](../README_en.md)

> Presentation-only translation of the unchanged Japanese source. Source SHA256: `531fee38939b848a58a7b2d4d98a59ea927f72f80a0afeca2ceb94770a057616`. Numbers, part IDs, equations, code and qualification limits are retained; this is not a new engineering revision.

**Instructions for comparative prototypes to be read with drawings. Physical assembly, printing and wind tests have not been performed.** Do not infer unknown purchased-part dimensions, materials or tightening specifications from simplified CAD.

[BOM A](BOM_A.csv) / [B](BOM_B.csv) / [C](BOM_C.csv) govern IDs, quantities and cut lengths. Only `printed` parts are printable in each `STL/Ver.3/A|B|C`; `purchased`/`cut_to_length` are purchased/fabricated. The two Q-prefixed types are fit coupons with assembly quantity 0.

Coordinates: **X axial, Y leg travel plane, Z height**. Left is −X and right +X, not the apparent front/rear. Mirrored leg triangles carry `_R`.

## Tools and prerequisites

Use a caliper, roughly 0.05/0.1 mm shims/feeler gauges, a straight alignment rod, 2.5/3 mm hex keys and 5.5/7 mm small wrenches. M4 countersunk/M4 button heads nominally use 2.5 mm; ordinary M4 cap heads and the specified hub use 3 mm. Check actual purchased fasteners.

REX shafts require cutting/end finishing to BOM lengths and axial M4 taps at both ends. Without suitable fixtures/experience, investigate pre-machined parts or machining services. The specified cut lengths are not a claim of catalog stock.

Print at **100%, mm**, without applying historical 150% again. Flat faces of gears, frames, forks and legs face the bed; cups use an end face. STLs are oriented with minimum Z=0. Determine local infill, dimensional compensation and cup brims using coupons. Unverified slicer settings do not guarantee strength or mass.

A's largest frame is about **254.4 × 256 mm**, excluding brims and edge margins on a 256 mm-square bed. Check the actual usable/forbidden regions in the slicer first. Scaling down to fit would break purchased-part interfaces; a larger usable area or separately designed split is needed. Print success is not claimed.

## Numbered assembly sequence

1. **Check both coupons first.** Use `Q_BEARING_FIT`'s 21.9/22.1/22.3 mm pockets and `Q_JOINT_FIT`'s holes against actual bearings, shafts and bushes. The 22.2 mm seat is an FDM-compensated starting point, not guaranteed fit. Do not use excessive-play or splitting press-fit combinations.

2. **Sort shafts, sleeves and spacers.** Separate intermediate REX shafts, end shafts, rotor shaft, 6 mm fixed shaft and M4 tie rods by BOM ID. Similar tube lengths have different roles. Finish ends parallel, avoiding burr loads on inner rings/plastic. Check M4 shaft-end engagement without bottoming.

3. **Insert frame/retainer nuts first.** Insert nuts in `P_FRAME_LEFT/RIGHT/CORE/FRONT_LEFT/FRONT_RIGHT`'s M3 hex seats while backs are open. Apply bearing insertion force to outer rings. `P_BEARING_RETAINER` retains only the outer ring; shafts/inner-ring spacers pass freely through the central 20.2 mm opening. Do not clamp inner rings or shields.

4. **Prepare input-bearing carriages for A only.** Insert M3 retainer nuts behind the three `P_INPUT_CARRIAGE_*` parts, then bearings and retainers. Main-frame/left-front-carrier input holes are 28 mm clearances, not bearing seats. Loosely fasten four M4 countersunk screws in each carriage's slots, with flush heads and rear washers/locknuts. Do not finalize tension.

5. **Build the rotor independently.** A/C use `P_ROTOR_CORE`, integral `P_ROTOR_YOKE` and two cups, not stacked thin arms. Fasten two M4 at fork roots and M3 at cup ends through open nut seats. Opposite ends use `_R` hole placement. B fastens cups directly to small end plates. Four M4 bolts attach hubs; adhesive does not transmit torque.

6. **Prepare six mirrored/nonmirrored legs.** Correctly combine AB/AC/PC/DE rods with PBD/CEF triangles. At B/C/D/E joints, 3.2 mm metal sleeves slightly exceed 3 mm plastic. Check by hand that tightening stops on metal without locking plastic joints. Threads are not sliding surfaces. Distinguish P's sleeve for the 6 mm fixed shaft.

7. **Assemble three shared cranks.** Fasten hubs to paired `P_CRANK_CHEEK` cheeks with countersunk M4, heads clear of rod travel. Align **purchased REX hub flats**, not only the square holes. Canonical shaft corner reference is 15°; opposing flipped hubs index another 90°. Rotating 90° preserves the four mounting holes. Do not force shafts or change crank phase. Recess M4 button heads and thin 12 mm-OD end washers. Between cheeks place the table's 20 mm stack, double-supported by M4×45 pins, washers and locknuts. Operate end stops in the reference pose where legs do not block the main axis.

8. **Close the mechanism progressively from −X.** Main left frame → crank/opposing legs → next bearing frame → next crank. Fit sleeves, spacers and aluminum tubes in order on the 6 mm fixed shaft and two M4 tie rods. **Do not pass a 32 mm hub through a 8 mm bearing bore.** Install each bay's hub/shaft before closing its neighboring frame. Cranks are outer 0°, center 180°, outer 0°. Check intermediate REX shafts and every cheek phase.

9. **Insert rotor/transfer shafts and close the last frame.** Place the rotor between supports and slide the last frame over free shaft ends. Transfer shaft M1 and B's M2 avoid leg/rotor motion. Align with a rod and progressively tighten tie rods. Do not jam fixed-shaft spacers or preload multiple outer rings axially.

10. **Install shoes and replaceable soles.** Attach each shoe with M3 through F's metal sleeve without locking pitch rotation. Two ties sit in shallow sole grooves without excessive underside projection. B's CEF axial position differs from A/C; do not reuse their spacers. Match stage sides/layers rather than hiding center-of-mass issues with shoe width.

11. **Install side stages from the main frame outward.** Fit four M4 case rods, tubes and guard back plates in sequence; nonmounting guard regions have actual passage holes. Prefasten all four hub/gear screws outside the case, following step 7's flat reference and flipped indexing. Do not rely on reaching rear screws after inserting a gear. On B's right, **finish S1 and its window before S3**. Left S2 mounts to the transfer shaft. Fasten outermost windows before front carriers. Temporary carrier fitting for hand rotation/A alignment must not block window-screw access during fastening.

12. **Install and adjust A's belt.** Mount 24T using aligned manufacturer through-holes/counterbores, not a bolt forced through two threaded interfaces. Align grooves with 48T and fit the 520×9 mm belt. An open front carrier avoids stretching over flanges. Temporarily refit the carrier, align three carriages with one rod and adjust tension. Record slots; **remove the carrier with carriages/bearings as a unit to fasten the window**, then refit. Separate from the shaft opening are **four 8.4 mm screw-clearance holes on a 36 mm square**. They clear four projecting M4×30 screws over ±1.5 mm travel and cannot be omitted. Preserve settings and recheck alignment/hand rotation. 10 N/span is assumed, not measured. M1 and secondary-gear centers stay fixed. A S1 uses **13 mm shaft hole and M3×40**; spur windows use **10 mm and M3×35**. BOMs/templates follow these stage-specific values.

13. **Adjust positioning/retention and close cases.** Spacers/collars act only on designated locating inner rings of intermediate/rotor shafts. Main cranks use hub/collar/end-stop combinations. Measure nominal 0.2 mm play; do not tighten floating bearings. Follow hub manufacturer's tightening instructions. Check directions/ratio during temporary assembly, then **fasten windows, refit front carriers, and complete end stops/case fastening last**. Retain main-frame bearings/hubs; hand-support rotating parts or use suitable stands while carriers are off, without driving them. Guards are containment concepts, not certified finger/impact protection.

14. **Remove front carriers first for disassembly.** Stop wind/drive input and support machine/rotating parts. Release accessible end stops and outer case-rod fastening; **pull front carriers outward as bearing/retainer units, then outer window → hub fasteners → outer stage → inner window/stage**. Retain main-frame bearings/locators and prevent shafts/rotors falling. Remove A's carriages with the carrier, preserving slot settings and rechecking alignment on return. In B, remove S3's window, gear, hub, back plate and spacers before S1's window. Do not pass hubs/pulleys through bearing bores. Rotor removal also reverses main-frame assembly. Simultaneous video motion does not waive order or support.

## Shared-crank 20 mm stack

| Order | Axial length | Function |
|---|---:|---|
| Washer | 0.5 mm | Cheek side |
| Sleeve | 3.2 mm | Nonmirrored AB |
| Washer | 0.5 mm | Separate sliding surfaces |
| Sleeve | 3.2 mm | Nonmirrored AC |
| Washer | 0.5 mm | Separation |
| Sleeve | 3.2 mm | Mirrored AB |
| Washer | 0.5 mm | Separation |
| Sleeve | 3.2 mm | Mirrored AC |
| Washer | 0.5 mm | Separation |
| Spacer | 4.7 mm | To opposite cheek |
| **Total** | **20.0 mm** | All four rods must rotate |

Long spacers/pins at ordinary B/C/D/E joints and the F shoe pin differ from this stack. Check BOM IDs and [canonical assembly A](assembly_A.json) / [B](assembly_B.json) / [C](assembly_C.json).

## Reading installation paths and tool space

Actual sections are in [drawings](drawings). Inspect bearing, hub and end-stop sections, not only completed renderings.

[CAD installation checks A](assembly_access_A.json) / [B](assembly_access_B.json) / [C](assembly_access_C.json) record nut extraction and axial gear/hub or belted-pulley paths in the listed disassembly states. They do not establish passage through installed front bearings.

| Location | Required sequence / space |
|---|---|
| Gear M4 flange screws | Join gear/hub outside the case first, avoiding later rear-face access |
| Hub tightening | Remove front carrier then outer window, support rotation, orient the shaft and insert a 3 mm key |
| Shaft-end M4 button head | Access from the shaft end; recess must not enter the rod sweep |
| Carriage M4 countersunk heads | Use canonical slots, align all three; alignment rod must withdraw after tightening |
| Guard-window nuts | Insert into hex seats while backs are open, not forced into closed cavities |
| Guard-window screws | Some are hidden by front carriers. Remove carriers first; in B, remove S3 window/stage before S1's window. Do not silently assume unusually short or high-angle tools |
| Cup/fork nuts | Insert from the cup's concave side; curved walls must clear axial nut/tool paths |
| Transfer shaft / hub | Insert transfer shaft, install hubs progressively, then close front carrier |

## Bench checklist — All unperformed

For physical measurements. Calculations/videos are not evidence that these tests occurred.

| Unperformed item | Record / stop condition |
|---|---|
| Fit test | Outer-ring seats, shafts/bushes and bores. Do not proceed with cracks, excessive play or forceful press fits |
| Marked torque transmission | Continuous marks across shaft/hub/gear; start at low load. Do not conceal slip with adhesive |
| Axial play | Physically measure cold, starting around 0.1–0.3 mm; reset for manufacturer/actual conditions. Stop if tightening sharply increases resistance |
| Retention | End stops, collars, four gear bolts and case: check escape/loosening under low hand load, not to destruction |
| Unloaded stage rotation | Record starting resistance separately before/after leg connection and belt-tension changes |
| Full-turn hand rotation | At least two cycles with all legs. Stop for interference, catching or excessive play in rods, shafts, tubes, cases or shoes |
| Crank torque versus angle | Measure several angles with a small force gauge and known lever arm; convert `力 × 腕長` units if needed |
| Mass and center of mass | Physical measurements, not just slicer estimates; include part-mass differences, cables and additions |
| Bench walking | Material-point slip, individual foot loads, passive shoe rotation, tipping and frame bending; record differences from video |
| Rotor alone | Static torque with recorded airspeed, direction and rotor angle; record zero/reverse torque at adverse angles too |

Free wind-driven walking follows these checks and assessment of retention/tipping risk. 3D prints can break and eject parts; do not run an unverified large rotor unattended near people. No purchasing, printing, equipment operation or wind test was performed here.

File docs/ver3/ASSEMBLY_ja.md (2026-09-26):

# Ver.3 — 組立・装着経路・ベンチ確認

**図面を見て組める比較試作の手順です。現物での組立確認・印刷・風力試験は未実施です。** 不明な購入品の寸法や材料、締付仕様を、CAD の簡略表示から決めないでください。

部品番号・数量・切断長さは [BOM A](BOM_A.csv) / [B](BOM_B.csv) / [C](BOM_C.csv) が正本です。`printed` の部品だけが各 `STL/Ver.3/A|B|C` の印刷対象。`purchased` と `cut_to_length` は購入／加工品です。Q から始まる二種類はフィット試験片で、組立数量 0 としています。

座標は **X＝軸方向、Y＝脚の進行平面、Z＝高さ**。左端は −X、右端は +X です。機体の見た目の前後と混同しないでください。左右鏡映した脚三角形には `_R` を付けています。

## 工具と事前条件

ノギス、0.05/0.1 mm 程度のシム・すきまゲージ、まっすぐな芯出し棒、2.5 mm と 3 mm 六角棒レンチ、5.5/7 mm の小型スパナを用意します。M4 皿頭・M4 ボタン頭は 2.5 mm、M4 通常キャップ頭と指定ハブの締結は 3 mm が基準です。実購入ねじで照合してください。

REX 軸は BOM の長さへ切断・端面仕上げし、両端に M4 の軸方向タップを加工する仕様です。適切な治具と加工経験がない場合は加工済み品／加工サービスを確認してください。カタログにその切断長さが在庫しているという意味ではありません。

印刷は **100%、mm**。過去の 150% 設定を追加しません。歯車・フレーム・フォーク・脚は平らな面をベッドへ、カップは端面をベッドへ。STL は最低 Z を 0 にした向きです。軸受座・ハブ締結部・薄いリンクなどの局所充填、寸法補正、カップのブリムは試験片で決めます。未確認のスライサー設定から強度や質量を保証しません。

A の最大フレームは約 **254.4 × 256 mm**で、256 mm 角の造形面に対するブリムや端部余白を含みません。使用する機械の実際の使用可能範囲・禁止領域をスライサーで先に確認してください。入らない場合に倍率だけ縮小すると購入部品が合わなくなるため、より大きい使用可能面か、別途の分割設計が必要です。ここでは造形できたとは主張しません。

## 番号付き組立順

1. **二つの試験片を先に確認する。** `Q_BEARING_FIT` の 21.9/22.1/22.3 mm ポケット、`Q_JOINT_FIT` の穴を使い、実購入の軸受・軸・ブッシュに合わせます。図面の 22.2 mm 座は FDM 補正を含む出発点で、実物がその径なら適切という保証ではありません。過大なガタや圧入で割れる組合せを本体へ使わないでください。

2. **軸・スリーブ・スペーサを仕分ける。** 中間 REX 軸、両端軸、風車軸、6 mm 固定軸、M4 タイロッドを BOM の部品 ID で分けます。切断チューブの長さは似ていても役割が異なります。端面を平行に仕上げ、バリで内輪や樹脂を押さないようにします。M4 軸端穴はボルトが底付きせず必要なねじかかりを得るか確認します。

3. **フレームと押さえのナットを先に入れる。** `P_FRAME_LEFT/RIGHT/CORE/FRONT_LEFT/FRONT_RIGHT` の M3 六角座へ、背面が開いている間にナットを入れます。軸受を入れる力は外輪に加えます。`P_BEARING_RETAINER` は外輪だけを保持し、中央 20.2 mm 開口から軸・内輪スペーサが自由に通ることを確認します。キャップを締めて内輪やシールドまで挟まないでください。

4. **A だけは入力軸受キャリッジを準備する。** 三つの `P_INPUT_CARRIAGE_*` へ M3 の押さえ用ナットを裏から入れ、軸受と押さえを取り付けます。主フレーム／左前キャリアの入力軸部は 28 mm の逃げ穴で、軸受座そのものではありません。キャリッジを四本の M4 皿頭ねじで長穴へ仮止めし、まだ張力調整を固定しません。皿頭は面一、裏側は座金と緩み止めナットです。

5. **風車を独立したサブアセンブリとして組む。** A/C は `P_ROTOR_CORE`、一体の `P_ROTOR_YOKE`、二つのカップを使います。別々の細い腕を重ねる構造ではありません。フォーク根元の二本の M4、カップ端の M3 を、開口しているナット座から締結します。反対端は `_R` の穴配置です。B は小径の端板へ直接カップを止めます。ハブは四本の M4 で端板へ結合します。接着剤をトルク伝達に使いません。

6. **六脚を非鏡映／鏡映で分けて仮組みする。** AB、AC、PC、DE 棒と PBD、CEF 三角形を正しい組合せにします。B/C/D/E の関節は、3 mm の樹脂を 3.2 mm の金属スリーブがわずかに越える構成です。ねじを締めても金属スリーブ・スペーサ側で止まり、樹脂の関節を固定しないことを手で確かめます。ねじ山を直接の摺動面にしません。P の 6 mm 固定軸用スリーブとは取り違えないでください。

7. **三つの共有クランクを組む。** 金属ハブを二枚の `P_CRANK_CHEEK` へ皿頭 M4 で固定します。頭は棒が通る側へ突出させません。ハブの四角い穴パターンだけでなく、**購入ハブの REX 対辺の向き**も合わせます。正規モデルの軸角は角部基準 15°、向かい合う反転ハブはさらに 90°インデックスした配置です。90°回しても四つの取付穴位置は変わりません。軸を無理にねじ込んだり、クランク位相をずらして合わせたりしないでください。REX 軸を入れ、M4 ボタン頭と 12 mm 外径の薄い軸端止め座金を凹部へ収めます。二枚の頬板の間には、下表の 20 mm 積層を置き、M4×45 のピン・座金・緩み止めナットで両持ちにします。軸端止めの操作は、脚が主軸中心を遮らない図面の基準姿勢で行います。

8. **主機構を −X から順に閉じる。** 主左フレーム → クランク・対向二脚 → 次の軸受フレーム → 次のクランク、の順に仮組みします。6 mm 固定軸と二本の M4 タイロッドには、対応する脚スリーブ・スペーサ・アルミチューブを順に通します。**32 mm ハブを 8 mm 軸受穴へ通そうとしない**でください。隣のフレームを閉じる前に、その区間のハブと軸を入れます。外側のクランクは 0°、中央は 180°、外側は 0°。二本の中間 REX 軸とすべての頬板の位相を確認します。

9. **風車軸と連絡軸を入れて最後の主フレームを閉じる。** 風車サブアセンブリを支持フレームの間へ置き、軸の自由端へ最後のフレームを通します。連絡軸 M1、B の M2 は脚・風車の可動域から離れた通り道です。芯出し棒で同軸度を確認し、段階的にタイロッドを締めます。固定軸のスペーサを突っ張らせたり、複数軸受の外輪を軸方向に締め付けたりしません。

10. **靴と交換可能な足裏を取り付ける。** F の金属スリーブを介して靴を M3 で取り付け、靴のピッチ関節を締め殺さないようにします。足裏は二本のタイで保持し、足裏の浅い溝へタイを収めて下面を極端に突き出させません。B は CEF 三角形の軸方向位置が A/C と異なるので、他案のスペーサを流用しません。靴の幅で重心問題を隠すのではなく、段の左右配置とレイヤー位置を合わせることが重要です。

11. **左右の段を、主フレーム側から外側へ取り付ける。** 四本のケース用 M4 ロッド、指定のチューブ、ガード背板を順に通します。ガードの非取付部分にはロッド／チューブの実際の通過穴があります。ハブと歯車の四本の取付ねじは、ケースの外で先に締結し、手順7の対辺基準と反転ハブのインデックスを守ります。後から歯車を通して裏側のねじへ工具を届かせる構成ではありません。B の右側では **S1 とその窓を先に完成させてから S3** を取り付けます。左 S2 は連絡軸へ取り付けます。最後の外側窓も前側軸受キャリアより先に締結します。前側キャリアは、手回しや A の芯出しのために仮組みできますが、窓ねじへの工具経路を塞いだまま窓を締めようとしないでください。

12. **A のベルトを装着・調整する。** 24T 側は、メーカー図の通し穴・座ぐりを使う角度でハブへ取り付けます。二つのねじ穴同士へ無理に一本のボルトを通して締め合わせないでください。48T 側とベルト溝の軸方向位置を揃え、520×9 mm ベルトを掛けます。前側キャリアを開けた状態なら、ベルトをフランジ越しに無理に伸ばす必要はありません。前側キャリアを仮組みし、三つの入力キャリッジを同一の芯出し棒で揃えて張力を調整します。長穴の設定位置を記録し、**前側キャリアはキャリッジ・軸受ごとのユニットとして一度外して窓を締結**してから戻します。窓には、軸穴とは別に**キャリッジ固定ねじ用の四つの8.4 mm逃げ穴（入力軸周囲の36 mm正方形）**があります。これは先端が窓を貫通する四本の M4×30 と ±1.5 mm の調整範囲を逃がすための孔で、省略できません。長穴の設定を不用意に緩めず、戻した後も芯出しと手回しを再確認します。10 N/スパンは計算用仮定で、実験で確認した張力ではありません。M1 と二次歯車の中心は固定したままです。A S1 の窓は **軸穴13 mm・M3×40**、平歯車段の窓は **軸穴10 mm・M3×35** で、BOM と型紙もこの段別仕様に従います。

13. **位置決め・抜け止めを調整してケースを閉じる。** 中間軸と風車軸は指定された位置決め軸受の内輪だけをスペーサとカラーで扱います。主クランク側はハブ・カラー・端部止めの組合せです。名目 0.2 mm の軸方向すきまを実物で測り、逃がす軸受を締め上げません。ハブの金属締付ねじはメーカー指定に従います。入力とクランクの回転方向・比率を仮組みで確認した後、**窓ねじを締めてから前側キャリアを戻し、最後に軸端止めとケース固定を完成**します。主フレーム内の軸受とハブを保持し、キャリアを外している間は風車・連絡軸・クランクを手や適切な受台で支え、駆動しません。ガードは飛散防止の概念部品で、認証された指保護・衝撃保護ではありません。

14. **分解は前側キャリアを先に外す。** 風・駆動入力を止め、本体と回転体を受台などで支えます。外側から操作できる軸端止めとケース用ロッドの外側固定を解放し、**前側キャリアを軸受・押さえ付きユニットとして外へ抜いてから、外側窓 → ハブ締結 → 外側段 → 内側窓／段**と進めます。主フレームの軸受と位置決め部は残し、長い軸やローターを自由落下させないでください。A の入力キャリッジは設定した長穴位置を変えずキャリアと一緒に外し、再取付後に芯を確認します。B では S3 の窓・歯車・ハブ・ガード背板と対応スペーサを取り除いてから S1 の窓を操作します。ハブやプーリーを軸受内径に通すのではありません。ローター全体を取り出す場合は主フレーム側の組立順まで戻します。分解動画の同時移動は説明用であり、この順序や回転体の支持を省略できるという意味ではありません。

## 共有クランクの 20 mm 積層

| 順序 | 軸方向長さ | 機能 |
|---|---:|---|
| 座金 | 0.5 mm | 頬板側 |
| スリーブ | 3.2 mm | 非鏡映 AB |
| 座金 | 0.5 mm | 摺動面の分離 |
| スリーブ | 3.2 mm | 非鏡映 AC |
| 座金 | 0.5 mm | 分離 |
| スリーブ | 3.2 mm | 鏡映 AB |
| 座金 | 0.5 mm | 分離 |
| スリーブ | 3.2 mm | 鏡映 AC |
| 座金 | 0.5 mm | 分離 |
| スペーサ | 4.7 mm | 反対側頬板まで |
| **合計** | **20.0 mm** | 四つの棒は回転できること |

通常関節 B/C/D/E の長いスペーサ、ピン長さ、F 靴のピンはこの積層とは別です。BOM の部品 ID と [正規組立 A](assembly_A.json) / [B](assembly_B.json) / [C](assembly_C.json) で照合してください。

## 装着経路と工具空間の読み方

実形状の断面は [drawings](drawings) にあります。軸受・ハブ・軸端止めの断面を、完成レンダリングだけでなく確認してください。

[装着経路の CAD 確認 A](assembly_access_A.json) / [B](assembly_access_B.json) / [C](assembly_access_C.json) は、表に明示した分解状態でのナット取り出しと歯車・ハブ／ベルト付きプーリーの軸方向経路を記録します。完成した前側軸受を通り抜けられるという確認ではありません。

| 部分 | 必要な順序・空間 |
|---|---|
| 歯車の M4 フランジねじ | ケース外で歯車＋ハブを先に結合。面の裏へ後からアクセスする必要をなくす |
| ハブの締付 | 前側キャリア、外側窓を順に外して回転体を支え、軸を必要な角度へ回して3 mm レンチを入れる |
| 軸端 M4 ボタン頭 | 軸端側からアクセス。凹部が棒の掃引を侵していないこと |
| キャリッジ M4 皿頭 | 正規の長穴を使い、三つを同じ軸線へ。締付後に芯出し棒を抜けること |
| ガード窓ナット | 背面が開いた段階で六角座へ入れる。閉じた空洞へナットを押し込む構造ではない |
| ガード窓ねじ | 一部が前側キャリアに隠れる。キャリアを先に外し、BではS3窓／段を外してからS1窓へ。特殊な極短・大角度工具を暗黙に仮定しない |
| カップ／フォークのナット | カップの凹側から入れる。曲面壁とナット・工具の軸方向経路が重ならないこと |
| 連絡軸・ハブ | 連絡軸を先に通し、ハブを段階的に取り付けてから前側キャリアを閉じる |

## ベンチ確認票 — すべて未実施

この欄は実測用です。計算や動画を、下の試験を実施した証拠にしません。

| 未実施項目 | 記録する内容／中止条件 |
|---|---|
| フィット試験 | 軸受外輪座、軸・ブッシュ、穴径。割れ、過大ガタ、強い圧入があれば本体へ進まない |
| 目印付きトルク伝達 | 軸・ハブ・歯車に連続する目印を付け、低い負荷から確認。接着で滑りを隠さない |
| 軸方向すきま | 冷間で約 0.1–0.3 mm を出発点に実測。メーカー条件・実物に応じて再設定。締付で急に重くなるなら停止 |
| 保持 | 軸端止め、カラー、四本の歯車ボルト、ケース。低い手荷重で抜け・緩みがないか。破壊まで試さない |
| 各段の空転 | 脚を接続する前後、ベルト張力変更前後で始動抵抗を分けて記録 |
| 全周の手回し | 全脚を最低二周期。棒、固定軸、チューブ、ケース、靴の干渉・引掛かり・大きなガタがあれば停止 |
| 角度別クランクトルク | 小さな力計と既知の腕長で複数角度を測る。必要なら `力 × 腕長` を単位換算して比較 |
| 質量・重心 | スライサー値だけでなく実測値。部品質量差やケーブル／追加部品を含める |
| 机上歩行 | 接地材料点の滑り、片脚荷重、靴の受動回転、転倒、フレームの曲がり。動画との違いを記録 |
| 風車単体 | 風速・方位・ローター角を記録した静的トルク。悪い角度のゼロ／逆トルクも記録 |

風での自由歩行はこれらの確認と保持・転倒リスクの評価後です。3D プリントの破損や部品飛散があり得るため、未検証の大風車を人の近くで無監督運転しないでください。ここでは購入、印刷、機器操作、風力試験を行っていません。

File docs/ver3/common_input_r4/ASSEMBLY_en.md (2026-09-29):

# Common input cartridge assembly and removal

[日本語 (original)](ASSEMBLY_ja.md) | **English** | [Document languages](../../README_en.md)

> Presentation-only translation of the unchanged Japanese source. Source SHA256: `75095ecd6051ff8c18796e634a3bb7f79c1be22b6fe8187d0f0531d7dced68d0`. Numbers, part IDs, equations, code and qualification limits are retained; this is not a new engineering revision.

**`v3-common-input-r4-01`. Partial-assembly sequence checked in actual CAD; printing, physical assembly and equipment operation are unperformed.** A new common input unit, not a drop-in V2 replacement. No rotor, legs, gear train or string/coin load fixture is included.

X is axial, Y lateral, Z up; X increases left to right. [BOM](BOM.csv) and [canonical instances/operation set](assembly.json) govern. Native labels match the names below.

## Preparation

Print in mm at 100%. Carrier rails face the bed; retainers/flange/coupon use flat faces. Horizontal carrier bearing bores need supports/bridging/cleaning not yet sliced. Do not press bearings into the body without cleaning and fit checks. Do not apply old 150% scaling.

Starting tool choices: 3 mm hex for external M4, 7 mm nut wrench, 2.5 mm hex for hub clamps and 3 mm hex for collar clamps. Check actual fasteners. Measuring tools are needed for fabrication, but user ownership is not assumed and no purchasing/measuring is performed for them. Unpublished tightening torque is not invented.

## Assembly sequence

1. **Check coupon and carrier.** `Q_BEARING_FIT` is a coupon with quantity 0, not installed. Starting from the corner with the 2×3 mm notch, compare seats 14.0/14.15/14.3/14.45 mm with real bearings and assess the body's nominal 14.2 mm bore. Do not bolt-force tight fits or push outer rings through inner-ring loading. 4 mounting holes exist, but mating material, mounting screws and fixing require separate confirmation.

2. **Insert `BEARING_LOC` from the left, then fit `CAP_LOC`.** Flange faces left; bearing X=14–19 mm, flange 14–15 mm, cap 10.7–13.7 mm. Use 2 M4×20 screws, 1 washers on each head/nut side and 1 locknut each. Seated caps retain nominal 0.30 mm outer-ring space. Before shafts/collars are inserted, nut tools have straight access.

3. **Insert `BEARING_FLOAT` from the right, then fit `CAP_FLOAT`.** Bearing nominal X=94–99 mm, flange facing right within the long X=97–100 mm groove; cap 100–103 mm. Use 2 M4×20 screws with head/nut washers and locknuts as on the left. Preserve ±1 mm outer-ring movement; do not add a right collar and axially clamp it.

4. **Preassemble `D_HUB`+`TEST_FLANGE` outside the carrier.** Match 4 holes on a 16 mm square; orient the 14 mm pilot into the 14.3 mm pocket, 2.15 mm deep. Use M4×12 and 1 mm washers, 4 each. Nominal engagement is 7 mm with 1 mm to the hub rear. Distinguish these 4 external screws from the hub's 2 clamp screws. Place the supported unit between bearings from above; its displayed final position does not imply shaft attachment.

5. **Place left locating spacers/collars.** `SPACER_OUT` at X=10–14 mm, `SPACER_IN` at 19–23 mm. Bosses face spacers. Nominal outer/inner collar boss faces are 9.9/23.1 mm, leaving 0.1 mm per side, 0.2 mm total play. The 2 collars are not distributed one per bearing. Support shaftless parts against falling.

6. **Release clamps and insert `SHAFT` from the left.** Pass outer collar, outer spacer, left bearing, inner spacer/collar, hub and right bearing. This is the manufacturer's 6 mm D-shaft/metal-hub pairing. Align flats; do not force insertion, file the shaft or enlarge CAD hubs. Distinguish tiny reference overlap from real fit as [explained](README_en.md).

7. **Check positions/free clearance, then fasten.** Hub body X=35–43 mm, test flange 43–47 mm. Leave space between inner collar/hub. Collar screws clamp the shaft, not preload bearings. Check outer-ring play, total inner-ring-stack clearance 0.10–0.30 mm, right outer-ring float and rotation after tightening. Stop for rubbing, sinking caps, increased resistance or strong misalignment. Specific torque/low starting resistance remain unverified.

8. **Finish as an unpowered checking stage.** This document does not direct dryer, motor or string-load operation. Separately verify bench fixing, purchased-part tightening, physical fits and protection. Apparently free unloaded motion does not qualify supply torque, all-angle self-starting or 30 cm walking.

## Removal sequence

Actual-CAD explanatory removal layout

With power absent, all movement stopped and parts supported, release hub/collar clamps. **Extract the shaft left first**, then lift out the hub/test-flange unit; remove inner collar/spacers after the shaft too. Do not pass a 32 mm hub through a 6 mm bearing bore or lift it with the shaft retained.

For explanation, the figure offsets the shaft 124 mm left, flange 50 mm up and collars sideways. Not a simultaneous-motion instruction. Leftward shaft and upward flange paths are separate entries in `assembly_access.json`. Verify D-interface release and real fit using manufacturer instructions and physical parts.

Remove rotating parts before accessing cap screws/nuts to remove bearings/caps. Left bearing exits left, right exits right. Do not assume a long nut-driver path while the hub remains inside the carrier.

## Tool paths and tolerances

`assembly_access.json` checks a 7 mm nut driver with OD 12 mm/length 28 mm and key-shaft envelopes diameter 4 mm, lengths 26/28 mm. Clamp access is recorded from the upper half-space with the entire rotating assembly at the same selected stop angle—not automatic rotation during work. Actual tool/finger shape and all-angle usability are not guaranteed.

Cap-seat indentation/tightening deformation is unmeasured. Acceptance calculations allow cap compression/sinking up to 0.05 mm; exceeding it invalidates the assumptions. **Crushing plastic to fit or eliminating play by tightening is not assumed.** Check metal inner/outer contact faces, side-specific tolerances and thermal/deflection allowances separately.

Even with cartridge geometry, quantities and paths defined, the three new whole machines, actual rotor capture efficiency and physical part friction remain future work.

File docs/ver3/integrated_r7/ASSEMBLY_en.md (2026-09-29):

# Common assembly — Whole-machine r7

[日本語 (original)](ASSEMBLY_ja.md) | **English** | [Document languages](../../README_en.md)

> Presentation-only translation of the unchanged Japanese source. Source SHA256: `b0b41df69184339e29f430740899f1e2cad6e5a9525b19df65f16457672dd69d`. Numbers, part IDs, equations, code and qualification limits are retained; this is not a new engineering revision.

**Assembly planning and finite CAD-path documentation.** Actual assembly, printing, tightening and starting tests are unperformed. Follow included/absent parts and check results in each design's `assembly_access.json`/`gait_motion.json`; do not relabel failed operations as passes.

[r7-16 floor correction](FLOOR_CORRECTION_en.md) changes C's stages and every design's PET lower edges/rocker-pin region. The old slice1 “geometry unchanged” statement applies only to that revision.

After R7-I1, fixed path inventories are automatically derived by replaying `orderedOperations`. Later fasteners are added after explicit boundaries. Workbench preparation contains only `prepareOnly` parts in an independent scene. Installed parts cannot be hidden to force PASS. [Review/corrections](REVIEW_en.md)

Only the input shaft is imported commercial 6D. Downstream uses domestic 5 mm-AF brass, NMB bearings, Hirosugi smooth metal sleeves, SAMINI springs and domestic screws. Addressing V2 relative shaft/rotor/gear slip, the input uses a metal D-hub and downstream actual hex sections. Threads are not sliding surfaces.

## Materials, tools and fabrication conditions

Each `BOM.csv` lists used quantities; `purchase_lots.json` lists purchase units, surplus and materials cost. Coupons/stand are separate in `common/accessories.json`, included in cost but excluded from walking mass. Shared purchase for 3 machines counts 1 common coupon/stand set.

Individual first-purchase estimates assume JPY 160/USD, filament JPY 3,000/kg and factor 1.2 on solids plus initial accessories. On 2026-09-28, **about JPY 24,000 in materials per 1 machine** was approved. Shipping, unresolved taxes and unowned tools such as DN-03 at about JPY 396 are separate. Not actual sliced consumption; extra supports/failures may exceed budget. Use same-revision sensitivities in each `purchase_lots.json`, not shared-purchase averages. Old JPY 23,000 versions remain historical.

Imports are limited to input parts/fastener lots. Surplus M4 screws/nuts also serve downstream caps; imported shafts/hubs are not duplicated on every axis. Used quantities and purchased lots such as 25-packs are separate.

Assumed tools: 1.5/2.5/3 mm hex keys, 4/5.5/7 mm small wrenches, hacksaw, file, measuring tools and PET cutter. Ownership/actual envelopes are unverified; no purchases/operations occurred. Do not substitute thin homemade tools or force insertion when specified tools do not fit.

B's final-stage right nut clearance was checked with a 5.5 mm tool-tip model of width ≤7.6 mm and thickness ≤1.8 mm. This does not verify an actual commercial tool/handle. Do not assume a larger tool fits; check `B/retainer_tool_access.json` conditions first.

- The 6D input shaft, 140 mm long, needs no cutting/end tapping.
- Domestic hex stock: main shafts 100 mm, intermediate shafts 58 mm. Check 58 mm stock within ±0.5 mm after finishing. Short ends are canonical PET-insertion geometry; do not independently lengthen shafts/STLs.
- First use coupons for bore diameter, 13 mm guide length, 8 mm round journal and actual tooth form. Manufacturer tolerances, printer compensation and layer strength are unqualified.
- A/B and C pair 2 use m1/25°. Only C pair 1 uses m0.9/20°, 12/156 teeth and shifts +0.35/−0.35. Do not mix with old C or A/B mating gears. About 0.53 mm tips require actual-layer/coupon checks; closed solids/contact ratio do not qualify printing.
- Do not enlarge the 6D metal hub to eliminate tiny nominal STEP overlaps during finishing. Open/clamped state, actual fit and tightening are separate unresolved matters.

After approval, official OrcaSlicer 2.4.2 was installed separately and [5 representative actual slices](SLICING_en.md) inspected. P1S/0.4 mm/PETG are inspection assumptions, not verified hardware matches. A/C input-pinion teeth begin 10 mm above the bed in exported orientation and need supports. The 2 checked gears retain 0.2 mm bottom support spanning bores; removal, bore/tooth-bottom finishing and fit remain necessary. No printer connection, transmission or printing occurred. Not whole-machine print qualification; see `slicing_status.json`.

## Sequence

1. **Prepare separate left/right frames.** Large compound gears are not forced through already joined frames. Identify bearings, caps, round journals, hex keys and joint faces; prepare parts inserted from outside first.
2. **Prepare left retention and downstream drive.** Insert left-crank journals into left bearings; place metal hex shafts, compound gears and left intermediate stops. Do not project clamp screws/nuts before passing parts. Right ends of 58 mm intermediate shafts and printed journals lie inside the upper PET plane.
3. **Close the right frame** following `frame_right_close`. Include bearings/caps/idlers positioned with the right frame among moving parts, and every already-installed left-side part among fixed parts. Right cranks, legs, input rotor/shaft and guards come later. Align front hex location and rear relieved key; add 4 M3 joints after seating. Keys locate the frame; bolt friction alone does not carry lateral load.
4. **Upper PET.** Temporarily withdraw the main shaft −53 mm in X; input shaft and idler outer-cap screws remain absent. Raise the panel from below offset **−4 mm in Y**, then seat at unchanged height along **Y=-4→0 mm**. Distinct from stage 07's X offset. Short intermediate journals, upper input notch and end-opening crossbar relief are prerequisites. Add waiting screws after seating. Do not ignore fixed parts/gears as invisible; check the stage inventory in JSON.
5. **Lower/side PET on both sides.** Install before right cranks and both leg sets. Existing cap fasteners are used, but steel-washer stacks—not PET compression spacers—carry clamping load. Large PET holes and outer retaining faces capture the sheet without adding bearing preload.
6. **Rotor into front basket.** Align metal D-hub, rotor, 4 M4 bolts and coaxial input pinion, entering through the open rear. The shaftless pinion requires hand-supported alignment. Diameter differs from capture width: axial root 4 mm, capture width 32 mm, end 2 mm, total 38 mm.
7. **Place rotor/front basket along two segments.** Before input shaft/rear guard, lower the complete rotor/hub/pinion/basket subassembly offset **+4 mm in X**. At final height, seat axially **X=+4→0 mm**. The 2 continuous segments retain identical moving/fixed inventories, including PET/fasteners from stages 04/05. Temporary collars/spacers are placed only afterward. This assembly-only offset does not change final positions, leg paths, wind or mass. Hand-support until shaft insertion; airborne self-support is not claimed.
8. **Insert input shaft.** Pass the 140 mm shaft through collars, spacers, pinion and metal hub. Distinguish manufacturer-specified 6D compatibility from nominal reference contact and actual open/clamped state.
9. **Rear guard and retention.** Pass forward-open rear-cap relief over fixed supports. After seating, add rear fasteners and 3 front-basket joints. Do not install later bolts early for checks or erase existing parts. Distinguish inner/outer-ring contact: locate on the left, leave right float. Guard removal does not require passing a closed integral cage over supports.
10. **Input collar orientation.** Follow each `inputCollarClocking`. Rotate the same 2 round-bore collars to reduce nominal gravitational imbalance without changing axial locations, quantity or mass. Print eccentricity, purchased centers of mass and dynamic balance remain unmeasured.
11. **Main shafts and crank phases.** 3 shafts retain 84 mm pitch and 42-tooth synchronization gears. C's 156-tooth gear moves from the floor-near final stage to the higher intermediate stage. C uses 13×12, final 144 teeth, total 156:1. Match shaft engagement/clamp direction. Left/right phases front-to-rear are 0/180, 180/0, 0/180°. Hex indexing differing by 60° is not the same phase.
12. **Legs, metal pins and feet.** Distinguish A/P/B/C/D/E sleeves and illustrated link layers. At P, hold the inner M2 head with a hex key; 2 nuts stay outside. No buried nut is tightened through a narrow window. M2 screws axially clamp sleeves, not lock printed links.

The separate assembly stand matches frame rail centers X=-39.5/32 mm and is removed for walking. This document does not authorize actual dryer/printer operation.

B's upper PET comprises 2 independent panels for 2 intermediate supports. Each has 2 retention points and its own used-part BOM entry; a mounting-bearing piece is not discarded as scrap. Procurement nests them as 1 cutting rectangle, neither inflating nor undercounting sheet area.

## Feet, springs and contact

Each foot uses 2 commercial 12-0721 springs, 20 mm metal guides and a passive rocker with 2 rolling-contact regions. Listed spring rate is 0.882 N/mm per spring, not obtained by adjusting assumed FDM modulus.

Rocker pins use 1 mm stepped seats placing washers against 8 mm metal-sleeve ends. **Commercial M2×12 and M2 nylon locknuts (4.5 mm AF, 2.5 mm high)** require neither precision cutting nor thin wrenches. Accepted screw lengths 11.7–12.3 mm give calculated protrusion ≥0.6 mm; actual chamfers, full threads and nylon engagement still require checking.

Preassemble only the CEF-integrated foot on a separate bench. Hold the M2 head with a normal 1.5 mm hex tool, use actual ENGINEER DN-03 on the nut, then add other links. DN-03: tip OD 8 mm/length 18 mm, socket depth 9 mm, shaft 75 mm, overall 145 mm, handle OD 13 mm. It matches 8.2 mm relief and local fork width 12.8 mm. Published dimensions/full envelope were checked, not ownership, physical operation or retention torque. [Sources/acceptance conditions](stock_fasteners_and_tools.json)

The nylon locknut is not demonstrated equivalent to the old 2 jam nuts in retention torque/reuse endurance. Retained performance after disassembly is not assumed; reassembly assumes new nuts.

Rocker axial width 4.4 mm plus small M4 steel washers on both sides (OD 8 mm, thickness 0.5 mm) totals 5.4 mm, preserving 0.6 mm end play inside the 6 mm fork. Do not mix old OD 9 mm/thickness 0.8 mm washers. Pad positions/radii/width, foot placement and spring travel are unchanged.

The foot module is physically mounted 4 mm forward of original F. Pad area/width and ballast are unchanged. A 8 mm option improved support but increased handoff potential-energy demand, so was rejected.

Mechanical stroke 6 mm compares with catalog allowable deflection 10.3 mm, estimated solid height 4.08 mm and free length 15 mm. Stops, guide overlap, screw ends and spring seats require actual-geometry checks. Stroke limits are not hidden by changing spring rate or floor height.

[A intermediate-stroke checks](A/foot_motion.json) store 0–6 mm in 0.5 mm steps plus rocker poses for the common foot. These are specified-part/sample checks separate from each whole-machine 216-pose check.

Loads and relative movement at contacts yield nonnegative slip work. Obtaining 3-leg support does not meet the old 3 mm slip target. Tolerance analysis covers finite link errors, both-end pin play, phase, floor height, spring rate, guide friction and input-couple cases—not a rigorous full-domain proof.

Airborne clearance is distance from the floor including body sinking caused by other feet's spring compression. Compression is not added twice to required clearance. A separate 0.9 mm margin covers untraversed floor/geometry.

## Remaining fastening and maintenance checks

No tightening torque is invented without manufacturer evidence. Fastener grades, plastic creep, printed bearing pressure/fits and actual tools remain to be checked. Guards are real BOM parts, not certified finger/fragment protection or impact-tested products.

Track cap checks, removal paths and sheet notches in actual files. A physically filed-to-fit part is not automatically the canonical CAD. Record required changes back into dimensions, mass and BOM.

`cad_validation.json`/`step_correspondence.json` check only native/STEP correspondence. They alone do not qualify assembly clearance; consult separate `static_collisions.json`, `gait_motion.json`, `assembly_access.json`, `rotating_clearance.json`. None certifies physical performance.

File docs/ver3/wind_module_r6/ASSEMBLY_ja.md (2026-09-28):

# 1モジュールの組立・脱着・基台条件

**版 `v3-wind-module-r6-01`。CADで確認した組立順です。実組立・動力運転・安全速度の確認はしていません。**

座標はXが軸方向、Yが左右、Zが上。全インスタンスの配置・数量は [assembly.json](assembly.json)、購入lotと個数は [BOM.csv](BOM.csv) が正本です。r4の試験フランジは使わず、ローターの根元板へ置き換えます。軸・軸受・Dハブ・カラーは同じ製品で、軸の切断・穴開け・端面タップは不要です。

## 部品と印刷

- `P_CARRIER`×1：高さ55mm軸用の一体キャリア。斜材4本も一体です。
- `P_ROTOR`×1：根元板4mm・羽根域32mm・端リング2mm、外形38mm。裸16羽根の単一ソリッドです。
- `P_CAP`×2：r4と同じ外輪押さえ。右側を締めて浮動を失わせないでください。
- `Q_BEARING_FIT`：本体数量0。r4のフィット試験片をそのまま再利用できます。

STLはmm・100%。キャリアはレール底面、ローターは根元板、押さえと試験片は平面をベッドへ向けています。ローター端リングの羽根間ブリッジ、根元パイロット座、横向き軸受穴は、サポートや造形補正を含めてスライサーで確認する必要があります。未スライスのため、サポート不要・任意プリンターでの造形成功を主張しません。

## 基台の4穴を先に扱う

取付穴はM4用4.5mm、X=6／114mm・Y=±18mm、**108×36mmパターン**です。キャップ・回転部が無い段階で、上から外径8mmの工具包絡が入ることを確認しています。組立後は左側のキャップねじなどが上方工具を遮る箇所があるので、最後に基台固定を済ませられると仮定しません。

**相手材、厚さ、裏打ち剛性、固定ねじ長さ、固定方法は未確定です。** このBOMに外部固定部を含めた運転可能な架台が揃っているわけではありません。構造計算の根元固定は、実際の相手材・締結が満たす必要のある境界条件です。未固定の模型や、手で持って支えた状態での動力運転を許可する資料ではありません。

## 手順

1. **フィットと基台条件を確認する。** 試験片で購入軸受と造形穴の相性を確認します。きつい穴を締結の力で引き込まないでください。取付方法を決めるまでは動力確認へ進めません。
2. **左の固定側を先に組む。** 軸受フランジを左へ向け、軸受→押さえの順です。M4×20×2本、頭／ナット側の各座金、緩み止めナットを使用します。内輪を締める蓋ではなく、キャリアの受け面へ着座する押さえです。
3. **右の浮動側を組む。** フランジを右へ向け、長い溝に軸方向移動を残します。押さえのねじは回転部を入れる前に締結します。右側に追加カラーを置いて左右軸受を締め上げません。
4. **Dハブとローターを外で先組みする。** 根元の14.3×2.15mm座に14×2mmパイロットを向け、16mm正方形の4穴を合わせます。M4×12と1mm座金を各4個使用し、名目ねじかかり7mmを取ります。ハブのクランプねじ2本と、ローターを留める外部4本は別です。
5. **固定側の2スペーサー・2カラーと軸を配置する。** r4と同じく、左軸受の前後に4mm鋼スペーサーを置き、2カラーで位置決めします。クランプを解放し、支持したローターユニットとD平面を合わせて軸を左から通します。メーカー指定のD組合せですが、きつい場合に削ったり無理に押したりしません。
6. **位置とすきまを合わせる。** ローター根元X=43mm、端リング終端X=81mm、軸高55mmです。固定側の内輪積層は全遊び0.20mmが名目、外輪の遊び0.30mmと右外輪の全2mm移動は別です。キャップの沈み・変形、軸受内部すきま、左右差を無視し、締付けでガタを消すことはしません。
7. **工具・保持を停止状態で確認する。** ローター根元4本へは40mmの端リング開口を通して3mm六角キーを入れます。計算では4mm径のキー包絡、約35.7mmの軸方向部分と上向き65mmハンドルが右支持の手前を通ることを確認しました。実際の曲げ半径・手指・工具長が同じとは限りません。ハブ／カラーのクランプキーも停止角を選んだ上方経路を別に確認します。
8. **ここで動力投入はしない。** 実基台固定、実はめあい・締付け、抵抗・バランス、防護・材料が未確認です。CADの回転包絡が空いていることからドライヤー駆動や600rpmの安全性を承認してはいません。

## 脱着

分離説明配置

無動力・完全停止・支持状態で、ハブとカラーのクランプを解放します。軸を完全に左へ抜いてから、ハブとローターの一体ユニットを上へ取り出します。羽根をつかんで曲げたり、端リングに紐を巻いて引いたりしません。32mm金属ハブを6mm軸受穴へ通す経路でもありません。

図は軸を左へ124mm、ローターユニットを上へ70mmなど離した説明配置で、一斉移動の指示ではありません。キャップを外す場合は回転部を先に退避し、ナット工具の空間を戻してください。基台固定の取外しも、最初の締結へ工具を戻せる状態にしてからです。

## 検査の範囲

全径100mm×幅38mmの円筒包絡で固定部との関係を確認しています。実羽根の厚さとテーパーは包絡内で、端リング中央20mm半径の空間と根元の実4穴は別に検査しています。ねじとDクランプ界面は、メーカーの締結を表す界面として記録し、微小な参照CAD交差を数値上消していません。

工具／挿入の経路は [assembly_access.json](assembly_access.json) の部分組立状態と標本が対象です。全手指、連続全公差、任意工具の操作性を証明するものではありません。外部基台の固定が未確定であることも、同ファイルとnative付随資料に保持しています。

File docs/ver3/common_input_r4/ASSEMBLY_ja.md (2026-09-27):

# 共通入力カートリッジの組立・脱着

**`v3-common-input-r4-01`。実CADで検査した部分組立順です。印刷・実組立・機器操作は未実施です。** これはV2への無加工差替え部品ではなく、新しい共通入力部です。ローター・脚・歯車列や、紐・硬貨の荷重治具は含みません。

座標はX＝軸、Y＝左右、Z＝上。左から右へXが増えます。[BOM](BOM.csv) と [正規インスタンス・手順集合](assembly.json) を正本にしてください。ネイティブのラベルは以下の部品名と一致します。

## 準備

印刷はmm、100%。キャリアはレール底面をベッド側、押さえ・フランジ・試験片は平面をベッド側にしたSTLです。キャリアの軸受穴は横向きで、サポート／ブリッジ／清掃方法は未スライスです。穴の清掃とフィット確認なしに本体へ軸受を押し込みません。従来の150%設定を適用しません。

工具は外部M4用の3mm六角、ナット用7mm、購入ハブのクランプ用2.5mm六角、カラーのクランプ用3mm六角が出発点です。実購入のねじで確認します。寸法・すきまを確認する道具は製作時に必要ですが、現在ユーザーが持っていると仮定せず、購入や測定を代行していません。メーカーの公表数値がない締付トルクをここで創作しません。

## 組立順

1. **試験片とキャリアを確認。** `Q_BEARING_FIT` は数量0の試験片で本体に付けません。角に2×3mmの欠けがある端から14.0／14.15／14.3／14.45mmの順で座を実部品と比較し、本体の14.2mm名目穴が適切かを確認します。きつい穴をねじ締結の力で圧入したり、軸受内輪へ力を掛けて外輪を押し込んだりしません。本体取付穴は4つありますが、相手材と取付ねじの指定・固定を別途確認します。

2. **`BEARING_LOC`を左から入れ、`CAP_LOC`を付ける。** フランジを左向きとして、軸受はX=14～19mm、フランジは14～15mmです。キャップはX=10.7～13.7mm。M4×20を2本、座金を頭側／ナット側各1枚、緩み止めナット各1個で取り付けます。キャップをキャリアの座へ寄せても、外輪には名目0.30mmの空間が残ります。軸やカラーを入れる前ならナットへ一直線に工具が届きます。

3. **`BEARING_FLOAT`を右から入れ、`CAP_FLOAT`を付ける。** 軸受は名目X=94～99mm、フランジを右向きにします。フランジはX=97～100mmの長い溝の中を動きます。キャップは100～103mm。左と同じM4×20×2本、頭／ナット側座金、緩み止めナットを使います。外輪の名目±1mm移動を残し、カラーを右へ追加して軸方向に締めません。

4. **`D_HUB`＋`TEST_FLANGE`をキャリアの外で先組み。** 16mm正方形の4穴を合わせ、14mmパイロットを14.3mm・深2.15mmポケットへ向けます。M4×12と1mm座金各4個。名目ねじかかりは7mm、ハブ裏面まで1mmです。これらの外部4本と、ハブ自身の2本のクランプねじを取り違えません。先組みユニットを上から支点の間へ置きます。表示の完成位置は、軸にすでに固定したことを意味しません。

5. **左固定側のスペーサーとカラーを配置。** `SPACER_OUT`はX=10～14mm、`SPACER_IN`は19～23mm。カラーのボスを各スペーサーへ向けます。外側カラーのボス面9.9mm、内側カラー23.1mmが名目位置で、両側0.1mmずつ、計0.2mmの遊びを設けます。2つのカラーを左右の軸受に分配するのではありません。まだ軸がない部品を支持し、落下させません。

6. **クランプを解放し、`SHAFT`を左から入れる。** 外側カラー、外側スペーサー、左軸受、内側スペーサー／カラー、ハブの順に通し、右軸受まで通します。メーカー指定の6mm D軸と金属Dハブの組合せです。D平面の方向を合わせ、きつい場合に無理に押したり、軸を削ったり、ハブをCADで拡大したりしません。参照モデルの微小交差と現物の適合は[説明](README_ja.md)の区別に従います。

7. **位置と自由すきまを確認して固定。** ハブ本体はX=35～43mm、試験フランジは43～47mm。内側カラーとハブの間にも空間を残します。カラーねじは軸へ固定するためのもので、軸受へ押し付けて予圧を加える調整ではありません。外輪の遊び・内輪積層の全0.10～0.30mmすきま・右外輪の移動・締付後の回り方を確認します。部品がこすれる、押さえが沈む、締付けで重くなる、強い芯ずれがある場合は進めません。特定の締付トルクや低い始動抵抗は未確認です。

8. **動力を入れない確認段階として完了。** この資料からドライヤー、モーター、紐荷重の操作へ進む指示はありません。机上固定、購入部の締付仕様、現物フィット、必要な防護を別途確認します。無負荷で軽く見えることを、供給トルク・全角自己始動・30cm歩行の合格とはしません。

## 脱着の順序

実CADからの脱着説明配置

動力を使っていない・完全停止した支持状態で、ハブとカラーのクランプを解放します。**軸を左へ抜いてから**、ハブ／試験フランジの一体ユニットを上へ取り出します。内側カラー・スペーサーも軸が抜けた後に取り出します。32mmハブを6mm軸受穴へ通したり、軸を残したまま上へ引き抜いたりしません。

図では説明のため軸を124mm左、先組みフランジを50mm上、カラー類を横へ離してあります。一斉にその方向へ動かす手順ではありません。軸の左抜き、フランジの上抜きの各経路は `assembly_access.json` の別項目です。D界面の解除状態／実はめあいはメーカー指定と現物で確認します。

軸受やキャップを外す場合は、先にこれら回転部を取り除き、キャップのねじとナットへ工具を戻します。左軸受は左、右軸受は右へ抜く経路です。ハブがキャリア内にあるままナットドライバーを長く差し込めると仮定しません。

## 工具経路と公差の読み方

`assembly_access.json` には、7mmナットドライバーを外径12mm・長さ28mm、キー軸を直径4mm・長さ26／28mmの包絡で確認した結果があります。クランプは回転体一式を同じ停止角へ合わせたときに、上半空間からアクセスできる角度を記録しています。作業中に自動で回転させる意味ではありません。手持ち工具の外形、手指、全角度での操作性を保証しません。

左右のキャップ座の押し込み・締結変形は実測していません。寸法受入計算はキャップの圧縮／沈みを0.05mmまでと置いており、それを超えた場合は前提外です。**樹脂を押し潰して寸法を合わせる、ガタを締付けで消すことを前提にしません。** 金属の外輪・内輪の当たり面、左右の公差、熱・たわみの余白は別々に確認します。

このカートリッジで形状・個数・経路が確定しても、全機の新しい三案、実ローターの捕風効率、実部品の摩擦は次の工程として残ります。

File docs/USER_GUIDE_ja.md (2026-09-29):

# サイトと資料の使い方

[日本語](USER_GUIDE_ja.md) | [English](USER_GUIDE_en.md) | [資料の対応一覧](README_ja.md)

## ページを選ぶ

[日本語サイト](https://ktanino10.github.io/TeoJansen_Rhinoceros/)は従来のURLです。[English](https://ktanino10.github.io/TeoJansen_Rhinoceros/en/)は同じ内容の英語版です。各ページ上部の切替は、同じページ・選択案のクエリ・見出しアンカーを保持します。言語の選択にアカウント、通信による設定保存、アクセス解析は使いません。

| ページ | 内容と版 |
|---|---|
| [全体紹介](https://ktanino10.github.io/TeoJansen_Rhinoceros/index.html) | 現行Ver.3.1の画像・比較値・配布先を主入口に、Ver.1/2/3.0の履歴を分離 |
| [製作記録](https://ktanino10.github.io/TeoJansen_Rhinoceros/production.html) | Ver.1の工程と、記録が残るVer.2の改良・完成写真・当時のテスト |
| [Ver.3.0 初期比較案・履歴](https://ktanino10.github.io/TeoJansen_Rhinoceros/comparison.html) | 旧A300/B90/C180 mmのMatrix・CG・規定動画・旧ダウンロード |
| [Ver.3.0 旧360°・組立](https://ktanino10.github.io/TeoJansen_Rhinoceros/viewer.html) | 同じ旧版の全メッシュ・部品ID・原典対応工程。現行ではない |
| [計算資料](https://ktanino10.github.io/TeoJansen_Rhinoceros/calculations.html) | 別版r3の材料・構造・流体モデル、r4入力カートリッジ |
| [Ver.3.1 比較・360°・12工程](https://ktanino10.github.io/TeoJansen_Rhinoceros/r7.html) | 現行の床是正版A750/B785/C750＝2285部品。内部ID r7/floor2 |
| [Ver.3.1 連続歩行](https://ktanino10.github.io/TeoJansen_Rhinoceros/walking.html) | 同じ現行形状を使う、別版の運動学・準静的な表示モデルと日英動画 |

Ver.3.1は既存の床是正版の公開名で、設計原本の改訂ではありません。内部ID `v3-integrated-walkers-r7-16-floor2` と成果物・入力コミット・ハッシュは[出典契約](../site/r7-source.json)で追えます。動画のr7表記もこの形状を指します。`r7-floor2-walking-kinematic-v1` は同じ形状に追加した別版の姿勢モデルです。r2/r3/r4/r6は内部研究・部分設計のIDで、作品のVer.2やVer.3.1を意味しません。

古い `index.html#ver3` も現在はVer.3.1へ案内します。旧 `comparison.html`／`viewer.html` はVer.3.0履歴として残し、現行へのリンクを明示しています。[現行の配布資料](https://ktanino10.github.io/TeoJansen_Rhinoceros/index.html#downloads)と[旧配布資料](https://ktanino10.github.io/TeoJansen_Rhinoceros/comparison.html#downloads)は混用しません。

## 3Dと動画を操作する

案を選び「読み込む」を押すまで、3Dエンジン・GLB・運動データは取得しません。歩行は停止状態で始まります。ドラッグ／指1本で回転、ホイール／指2本で拡大・移動できます。3D領域へフォーカスすると矢印で回転、＋／−で拡大縮小、Homeで全体表示。組立ではShift＋矢印で移動、歩行ではSpaceで再生／停止できます。操作説明は各ビューの近くにもあります。

組立の「全完成」は画面上の参照状態で、実組立済みを意味しません。r7では「操作境界／経路標本」で在庫・一時取外し・同ID再挿入を追えます。別作業台の準備は本体の装着数量へ加算しません。JavaScriptやWebGLが使えない場合も、静的な工程・部品表・画像・資料を参照できます。

動画は自動再生しません。連続歩行の日本語ページには日本語注記版、英語ページには英語注記版を表示します。歩行のCCは既定で重ねず、利用者が任意にONにできます。選択済みのCCを繰り返し強制OFFにはしません。小さい画面では全画面表示・任意字幕・動画の近くの通常サイズ本文を利用してください。字幕の可読性を一律の縮小CSSで変更しません。

歩行動画は全案とも**規定入力120 rpm・時間圧縮16×・4周期**です。A約18秒/B約64秒/C約20秒、約37 cmの前進は計算表示で、実時間の歩行性能や実測距離ではありません。空中ロッカーの中立復帰と手続きばねは明示した表示仮定で、原解析の独立ロッカー角nullを変更しません。

[日英媒体の来歴](ver3/r7_walking_locales_v1/manifest.json)は、同じ運動・時刻から作った言語別の注記・poster・字幕を記録します。元の歩行モデル資料と初版の媒体・配信枠の記載は固定された履歴として保持し、現在の日英表示と区別しています。

## 資料・印刷データの凡例

主要18資料の英語版は日本語原本を変更しない対訳です。英語版冒頭に原本へのリンクとSHA256があります。[対応manifest](translation-manifest.json)に範囲とハッシュを記録しています。元READMEの日英ペアはVer.1/2の製作記録です。

- **CAD・STEP・STL・GLB**：日英で共通。言語のための再設計、再モデリング、部品の省略はしていません。
- **BOM 7点・数値JSON/CSV**：BOMの項目は既に英語・共通で、原本をそのまま共有します。数量・部品ID・SKU・価格・URLは不変。JSONの原注記は日本語の場合がありますが、主要解説は対訳資料を使えます。
- **Ver.1原図PDF**：[組立参考図](テオヤンセン2Dv1.pdf)／[詳細参考図](テオヤンセン2D図面最新.pdf)は**原図（日本語）**です。英訳図面やVer.2専用図面とは表示しません。記載のない寸法・公差・工程を写真から補いません。
- **r7のPET型紙・断面図**：部品IDと寸法の原本を共用。案・版・部品IDを照合し、記載のmm寸法を優先します。図の線・穴・寸法を翻訳のために変更していません。切断・工具条件は各案の説明と共通組立にあります。
- **写真・旧動画**：元の実物写真とCGの区別を維持。外部YouTube動画は元の言語で、再投稿していません。旧r7組立動画の焼込みラベルは英語で、日英の工程字幕を対応ページから使えます。

Ver.1/2の過去の倍率150%／脚160%をVer.3へ重ねません。Ver.3はmm・100%。代表スライスは限定したソフトウェア検査で、全機の印刷・支持除去・はめあいの認定ではありません。プリンターへの送信・印刷開始はしません。

## 判定と予算を読み分ける

現行Ver.3.1（内部r7/floor2）の部材費目安は**約24,000円／台**。個別初回A23,305.13円/B23,735.37円/C23,154.43円と、未保有DN-03約396円・送料・未確定税等は区別します。共同購入平均を個別費用へ置換せず、旧20,000円／23,000円条件はその版の履歴です。

`manufacturingRelease=false`、実機合格数0、実風・実自己始動・実30 cm歩行はUNKNOWNです。デジタルの有限標本PASSは、連続する全経路・全公差・CFD/FEM・耐久・実機運転の認定ではありません。使用材料や接着・硬化・工具は製品の指示と現物確認を優先し、過去の記録だけを安全保証にしないでください。

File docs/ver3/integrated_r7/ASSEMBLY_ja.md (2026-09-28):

# 共通組立手順 — 全機r7

これは**組立計画と有限CAD経路の資料**です。実際の組立・印刷・締付け・始動試験は未実施です。各案の `assembly_access.json` / `gait_motion.json` に記録された対象部品・不在部品・検査結果を優先し、FAILの手順を合格と読み替えないでください。

[r7-16の床干渉是正](FLOOR_CORRECTION_ja.md)ではCの段配分、各案のPET下縁とロッカーピン周辺を変更しています。旧slice1の「実体不変」という記録はその旧版に限ります。

独立統合レビューのR7-I1を受け、経路の固定側は工程の `orderedOperations` を再生した在庫から自動導出します。後付けの締結品は、明示した操作境界より後に追加します。別作業台での部分組立は `prepareOnly` の部品だけを持つ独立シーンです。工程から装着済み部品を隠してPASSにすることはできません。[レビューと是正記録](REVIEW_ja.md)

入力軸だけが既製6D輸入品です。下流は国内5mm-AF黄銅材、NMB軸受、廣杉の平滑金属スリーブ、SAMINIばね、国内ねじを使います。V2の「軸と風車・歯車の相対滑り」に対し、入力は金属Dハブ、下流は実際の六角断面で伝達します。ねじのねじ山は摺動面にしません。

## 部材・工具・製作条件

各案の `BOM.csv` は使用数量、`purchase_lots.json` は購入単位・余剰・材料費です。試験片と組立台は `common/accessories.json` の別枠で、費用に含め、歩行質量には入れません。3台共同購入では共通試験片・組立台を1組だけ計上します。

個別初回の設計見積は、仮為替160円/USD、印刷材料3,000円/kg、ソリッド＋初回付属品の材料係数1.2を基準にしています。2026-09-28に**1台の部材費目安約24,000円**が承認されました。送料・未確定税等、未保有のDN-03約396円等の工具費は別です。実スライスの消費量ではなく、サポート・不良分が増える場合まで予算内とは保証していません。共同購入平均と混ぜず、各 `purchase_lots.json` の同版感度欄を参照します。過去の23,000円版は履歴として保持します。

輸入購入は入力部の部品・締結品lotに限定します。そのM4ねじ・ナットの余剰を下流キャップにも使い、新たな輸入軸やハブを全軸へ複製していません。使う数量と購入する25個入り等のlotは別欄です。

工具は1.5/2.5/3mm六角キー、4/5.5/7mmの小型スパナ等、金のこ・やすり・寸法確認具、PET用カッター等を想定します。工具の保有と実外形は未確認で、購入や実機操作は行っていません。指定工具が入らない場合に、細い自作工具や強い押込みで代用しないでください。

B最終段の右保持ナットについては、5.5mm用工具の先端外幅7.6mm以下・厚さ1.8mm以下という条件で実形状との空間を確認しました。これは工具の先端モデルの結果であり、該当する市販工具や実ハンドルの適合確認ではありません。大きな工具が入るとは読み替えず、`B/retainer_tool_access.json` の条件を事前に確認します。

- 入力6D軸140mmは切断・端面タップ不要。
- 国内六角材は主軸100mm、中間軸58mm。58mm材は端面処理後±0.5mmを確認します。短い端部はPETパネル挿入のための正規形状で、軸・STLだけを個別に延長しません。
- まず内径・13mm案内長・8mm丸ジャーナル・実歯形の試験片を使用します。メーカー実寸公差、プリンターの補正、積層強度は未認定です。
- A/BとC第2対はm1・25°です。C第1対だけはm0.9・20°、12/156歯、転位+0.35/−0.35の対です。旧CやA/Bの相手と混用しません。約0.53mmの歯先は実層と試験片で確認する対象で、ソリッド閉鎖や接触比だけを造形合格にはしません。
- 仕上げの際に6D金属ハブを拡大して名目STEPの微小交差を消しません。開放/締結状態、現物はめあいと締付けは別の未確認事項です。

承認後に公式OrcaSlicer 2.4.2を専用領域へ導入し、[代表5点の実層](SLICING_ja.md)を確認しました。P1S／0.4mm／PETGは検査上の仮定で、実機との一致は未確認です。A/Cの入力ピニオンは書き出し姿勢で歯面が床から10mm上にあるため支持対象とします。確認した2つの歯車には、軸穴を横断する底面支持0.2mmが残り、除去後の穴・歯下縁・はめあい確認が必要です。プリンター接続・送信・印刷は行っていません。全機の造形合格とはせず、対象と設定は `slicing_status.json` を参照します。

## 手順

1. **左右フレームを分離して準備。** 左右を一体にしてから大きな複合歯車を無理に通す構造にはしていません。軸受、キャップ、丸ジャーナル、六角キー、接合面を識別し、フレームの外側から入れる部品を先に準備します。
2. **左側の保持と下流を準備。** 左クランクの丸ジャーナルを左軸受へ入れ、金属六角軸、複合歯車、中間軸の左ストッパーを配置します。クランプのねじ・ナットは、部品を通す前から大きく突き出させません。中間軸58mmの右端と印刷ジャーナル端は、上側PET面より内側に収まる形状です。
3. **右フレームを閉じる。** 組立経路の `frame_right_close` に従います。右フレームと同時に位置決めする軸受・キャップ・アイドラーを移動側へ含め、既に左側へ装着した全部品を固定側へ含めます。右クランク、脚、入力風車・入力軸、ガードは後工程です。前側の六角位置決めと後側の逃げ付きキーを合わせ、着座後に4本のM3継手を追加します。キーで位置を決め、ボルトの摩擦だけで横荷重を受けません。
4. **上側PETパネル。** 主軸をX方向へ一時的に−53mm引き込み、入力軸とアイドラー外輪キャップのねじをまだ入れない状態で、上側パネルを完成位置から**Y方向へ−4mm**ずらして下から上げ、同じ高さで**Y=-4→0mm**へ移して着座させます。これは工程07のX方向の退避とは別です。短い中間ジャーナル、上端の入力部切欠き、端へ開く横桟の逃げが前提です。待機していたねじは、パネル着座後に取り付けます。固定具や歯車を「見えない物」として無視せず、検査JSONの段階部品一覧を確認します。
5. **左右の下側・側面PET。** 右クランクと左右脚を組む前に装着します。既存キャップ締結部を使いますが、PETを軸受キャップの圧縮スペーサーにせず、金属ワッシャーの積層で締結荷重を受けます。PETは大きい穴と外側の保持面で捕捉され、締め過ぎによる軸受予圧を作らない配置です。
6. **前バスケットへ風車を入れる。** 金属Dハブ、風車、4本のM4と同軸の入力ピニオンを位置合わせし、開いた後面から前バスケットへ入れます。ピニオンはまだ軸で保持されていないため、位置合わせを手で支持する部分組立です。径と受風幅を混同しません。軸方向は根元4mm、受風幅32mm、端部2mm、合計38mmです。
7. **風車＋前バスケットを二段経路で配置。** 入力軸と後部ガードはまだ入れず、風車・ハブ・入力ピニオン・前バスケットの部分組立全体を、完成位置より**X方向へ+4mm**逃がして上から下ろします。高さが完成位置へ達したら、**X=+4→0mm**へ軸方向に戻して着座します。2区間は同じ部品・同じ固定在庫で連続します。工程04・05で装着したPET板と保持ねじを残したまま検査し、カラー・スペーサーの仮置きはこの着座後です。これは組立中だけの一時退避で、完成位置・脚軌道・風条件・質量は変更していません。軸を入れるまで手で支持し、空中に自己保持するとは扱いません。
8. **入力軸を通す。** 140mm軸を、カラー・スペーサー・入力ピニオン・金属ハブへ通します。名目Dハブ参照形状の接触は、メーカーが6D対応を示すことと、実物の開放/締結状態を区別します。
9. **後部ガードと保持。** 後部キャップの前方へ開いた逃げを固定支柱へ通し、着座後に後部キャップの締結品と前バスケットとの3か所の接合品を追加します。検査中から後付けボルトを装着済みにすることも、既存部品を消すこともしません。左右の軸受内輪/外輪の当たりを混同せず、左で位置決め、右に浮動余裕を残します。ガードを外すために閉じた一体ケージを支柱へ通す構造ではありません。
10. **入力カラーの向き。** 各案の `inputCollarClocking` の向きに合わせます。軸方向の位置・部品数・質量は変えず、同じ2個の丸穴カラーを回して名目重力不釣合いを減らします。現物の印刷偏心、購入品重心、動釣合いまで確認済みではありません。
11. **主軸とクランク位相。** 3本の主軸ピッチは84mm、同期歯車は42歯です。この寸法は保持し、Cの156歯は床に近い最終輪から高い中間段へ移しました。Cの段配分は13×12、最終144歯、総156:1です。軸の正係合と歯車のクランプ方向を基準に合わせます。左右脚の位相は、前後順に0/180、180/0、0/180°です。60°違いの六角穴位置を同じ位相とみなしません。
12. **脚、金属ピン、足。** A/P/B/C/D/Eのスリーブと、図示されたリンク層を混同しません。Pでは内側のM2ねじ頭を六角キーで保持し、2個のナットは外側です。埋まったナットを狭い窓から無理に締める形状にはしていません。M2ねじはスリーブを軸方向に締め、印刷リンクを挟んで固めません。

作業時の組立台は、実フレームの左右レール中心X=-39.5/32mmに対応する別部品です。歩行時に付けたままにしません。この資料はドライヤーや印刷機を実際に運転する許可ではありません。

Bの上側PETは、2つの中間軸支持部に対応した2枚の独立パネルです。各片に2か所の保持点があり、使用部品として別にBOMへ載せています。取り付け点を含む片を「切屑」として捨てたものではありません。購入時は1つの切出し矩形として割り付け、必要なシート量を水増しも過小計上もしません。

## 足・ばね・接地

各足は市販12-0721ばね2本、20mmの金属案内、2つの転がり接触部を持つ受動ロッカーです。ばね定数は表示値0.882N/mm/本で、FDMの仮弾性率を変えて得た数値ではありません。

ロッカーピンは8mm金属スリーブの端面へ座金を当てる1mm段付け座面を使用します。**市販M2×12とM2ナイロン緩み止めナット（対辺4.5mm、高さ2.5mm）**を使用し、精密切断と薄口スパナは不要です。ねじの受入長さ11.7～12.3mm等に対し先端突出0.6mm以上を計算していますが、現物の面取り・完全ねじ山・ナイロン部へのかかりを確認してから使用します。

CEF一体の足モジュールだけを先に別作業台で組みます。M2頭側を通常の1.5mm六角工具で保持し、実在するENGINEER DN-03をナット側に使用してから他の脚リンクを加えます。DN-03は作業端外径8mm/長さ18mm、穴深さ9mm、軸長75mm、全長145mm、柄径13mm。8.2mmの逃げと局所幅12.8mmのフォークに対応させています。公表寸法と全工具外形を確認しましたが、所有・実操作・実保持トルクは未確認です。[出典と受入条件](stock_fasteners_and_tools.json)

ナイロン緩み止めは、旧2個のジャムナットと保持トルクや再使用耐久まで実証同等という意味ではありません。本計画では分解後の性能維持を仮定せず、再組立時は新品ナットを使用する前提です。

ロッカーの軸方向幅4.4mmと両側の小形M4鋼座金（外径8mm、厚0.5mm）の合計は5.4mm。6mmのフォーク内側に対する自由すきま0.6mmを保持します。旧外径9mm／厚0.8mmの座金と混用しないでください。接地パッドの位置・半径・幅、足位置とばね行程は変えていません。

足モジュールは元のF基準から実際に4mm前方へ取り付けます。パッドの幅・面積は増やさず、重りも追加していません。8mm案は接地支持を改善する一方で接地切替の位置エネルギー要求を増やしたため採用していません。

機械的行程6mmに対し、カタログ許容たわみ10.3mm、推定密着高さ4.08mm、自由長15mmです。ストッパー、案内の重なり、ねじ端とばね座は実形状で確認する対象です。行程限界をばね定数や床の位置変更で隠しません。

共通の足については、[Aの中間行程チェック](A/foot_motion.json)にも0～6mmの0.5mm刻みとロッカー姿勢を保存しています。各全機の216姿勢チェックとは別の、指定部品・指定標本の確認です。

接地点ごとの荷重と相対移動から滑り仕事を非負で計上します。3脚支持が得られたことと、旧3mmの滑り目標を満たしたことは別です。公差解析はリンクの製作誤差、両端ピンすきま、位相、床の高さ、ばね定数、ガイド摩擦、入力偶力の有限ケースです。全公差域の厳密証明ではありません。

空中足のクリアランスは、他の足のばね圧縮による胴体沈下を反映した床からの距離です。圧縮量を必要クリアランスへもう一度加える二重計上はしません。別途、未通過床面と形状の余裕0.9mmを確保します。

## 締結・保守で残る確認

締付けトルクをメーカー根拠なく指定していません。ねじ強度区分、樹脂クリープ、実プリントの面圧・軸受はめあい、工具実外形は確認事項です。ガードは実部品としてBOMに含みますが、指・破片に対する規格認証や衝撃試験を済ませたものではありません。

各キャップの有限検査、取り外し経路、平面ガードの切欠きは実ファイルで追跡します。削って辻褄を合わせた現物を、元の正規CADと同じものとして扱わないでください。必要な現物修正は寸法・質量・BOMへ戻して記録します。

`cad_validation.json` / `step_correspondence.json` はnative/STEPの対応だけを検査する記録です。そのファイル単体では組立干渉を認定せず、別の `static_collisions.json`、`gait_motion.json`、`assembly_access.json`、`rotating_clearance.json` を参照します。いずれも現物性能の認定ではありません。

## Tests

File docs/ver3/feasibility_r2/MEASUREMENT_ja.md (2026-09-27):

# 最小の入力確認案 — 全機を先に作らない

**`v3-r2-feasibility-02`／未製作・未実施の計測仕様案です。** 機器操作、購入、印刷を実行した手順書ではありません。新しい測定モジュールの製造CADもまだありません。ドライヤーの改造、吹出口・吸込口の閉塞、高温設定、固定方法の変更を前提にしません。冷風条件とメーカー取扱説明書を守るユーザー側の判断・操作が別途必要です。

目的は、三案の全機を印刷する前に、**実際の距離・吹付位置で得られる入力が、設計を続ける価値のある範囲か**を調べることです。型番だけを繰り返し尋ねたり、スマートフォンの動画だけから風速を作ったりしません。

## A. 風速計がある場合

型番、冷風設定、ノズル有無、出口から風車面までの距離、吹付方向、計器の測定範囲・精度を記録します。風車予定面の中央だけでなく、中央／上下／左右と外側の点を測り、**どの幅に有効な流れがあるか**を確認します。計器の検出部が大きい場合は細い噴流を平均してしまうため、その寸法も必要です。

カタログ風量はこの分布の代わりになりません。また、流速分布が得られても戻り側の負トルクや漏れは残るので、風速だけで全角度自己始動を合格にはできません。

## B. 風速計がなく、荷重の質量を確認できる場合

次の**共通の小型風車試験モジュール**を候補とします。まず中間径90mmで入口を確認し、必要なら同じ支持に120/60mmのローターだけを交換します。90mmの結果を面積や半径の単純倍率で他径の合格値へ換算しません。

| 計画要素 | 仕様の出発点 | 確認してから製造する点 |
|---|---|---|
| 風車 | 径90×幅48mm、今回の羽根パラメータ | 実CAD・印刷・保持・材料特性、実寸外径 |
| 軸 | 既製6mm D、140mm | 実軸の直径・平面5.5mm、印刷D穴のはめあい |
| 軸受 | 同一の686ZZを2個、支持中心20/120mm | 13mm外輪座、内輪専用スペーサ、シールド非接触 |
| 保持 | 軸方向カラー2個と外輪保持 | 締付で抵抗を増やさないこと。カラーはトルクキーではない |
| 荷重ドラム | 有効半径30mmを出発点とする単層溝 | 紐を含む**実有効半径**を測る。複数巻きで半径を増やさない |
| 支持台・保護囲い | 最大ローター径も受ける台、取付耳、囲い | 固定した台・回転体保持・荷重の小さい移動範囲を設計。未検証の台を手で支えない |
| 記録 | 開始角、荷重、半径、支持の状態、スマートフォン動画 | スマートフォンは動きの記録用で、校正された力計・風速計ではない |

必要な購入品をほぼ風車・軸・軸受に限定し、脚も歯車も不要にする案です。取付け・囲い・台の固定が完成していない状態で運転を勧めるものではありません。重量を大きくしたり高速回転させたりする破壊試験も目的にしません。

### 荷重で示せるトルク

質量と有効半径から既知の負荷を作れます。単位を揃えると次の関係です。

```text
負荷トルク [mN·m] = 0.00980665 × 質量 [g] × 有効半径 [mm]
```

| 半径30mmでの換算例 | 名目負荷トルク |
|---|---:|
| 22g | 6.47mN·m |
| 50g | 14.71mN·m |
| 102g | 30.01mN·m |

**これは使用する荷重・運転の指示や、合格する重さではありません。** 読み取り分解能と質量精度は別です。半径もCAD値ではなく、紐の厚さ・一層の巻き方・荷重中の位置を含めます。たとえば1g単位でしか分からない小さい荷重では数%の差が生じます。合否に使う場合は誤差を引いたトルク下限と比べます。

錘・紐に直接風が当たる、台が動く、ドラムが側面へ擦る、紐が重なる、手で予め回す、といった条件では比較できません。型番不明の計りの分解能だけを「精度±1g」と扱いません。

### 摩擦の校正と「正味」の区別

無風条件で両回転方向・複数の開始角の始動抵抗と偏りを記録し、支持・ローター偏心・紐の抵抗を切り分ける必要があります。静止した力計の表示を一回引くだけでは、静摩擦の履歴を除けません。重りによる追加のラジアル荷重も軸受抵抗を増やすので、都合よく無負荷値へ補正しません。

このモジュールで観測する、**同じ2個の入力軸受を通った後の正味トルク**は、計算側の「入力軸受2個を除いた下流要求」と比較します。軸受の抵抗を測定側でも計算側でも二重に差し引きません。

| 現版の高抵抗条件に対する設計側の目標 | A | B | C |
|---|---:|---:|---:|
| 正味トルクの余裕2倍目標 | 約29.96mN·m | 約6.39mN·m | 約14.23mN·m |

**2倍は設計側が選んだ余裕です。ユーザーの実測済み合格条件ではありません。** 実質量・摩擦・支持を確定したら再計算します。上の換算例は測定誤差分の余裕を含まないため、表の数値に近いという理由だけで合格にはできません。最新の正確な値は各 `candidate_*.json` の `measurement_target_static_net_input_nm` を参照します。

## C. 最小確認から全角度確認へ

最初の少数角での結果は、入力の桁が足りるかを見る**足切り**にだけ使います。成功した一角から全角度成功を推定しません。

必要な記録は、風車ID／版、開始角、実距離、ノズルと方向、荷重と半径の上下限、無風抵抗、変位方向、台の動き、停止・逆回転の有無です。全角度を主張する段階では一周の細かい標本と弱い角度の追加確認が必要です。標本間の狭い死点、機体側のクランク位相、接地切替はさらに別の確認です。

回転できる場合でも、回転中の供給トルク・仕事・30cmの継続性を静止試験だけで証明しません。必要入力を測れたあとで、同じ支持・ローター・版を使った機体設計へ進みます。

## 現時点の扱い

風速計の有無、荷重を確認する手段、使用するプリンター／工具は未確定です。上のいずれの測定も実施していません。読み値をゼロや仮の風速で埋めず、[比較JSON](comparison.json) の測定欄と合格試作数0を維持します。

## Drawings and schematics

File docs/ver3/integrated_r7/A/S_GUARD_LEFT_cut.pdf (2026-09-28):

## A S_GUARD_LEFT

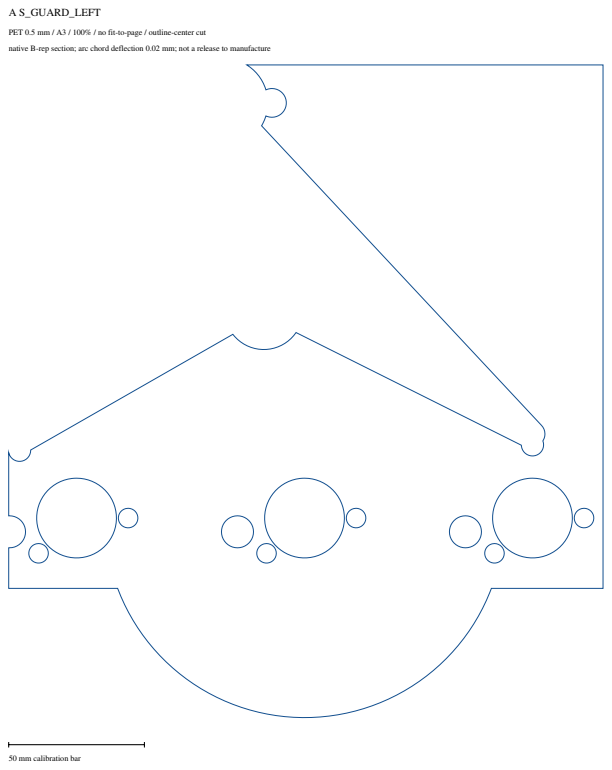
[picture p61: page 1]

PET 0.5 mm / A3 / 100% / no fit-to-page / outline-center cut
native B-rep section; arc chord deflection 0.02 mm; not a release to manufacture

50 mm calibration bar

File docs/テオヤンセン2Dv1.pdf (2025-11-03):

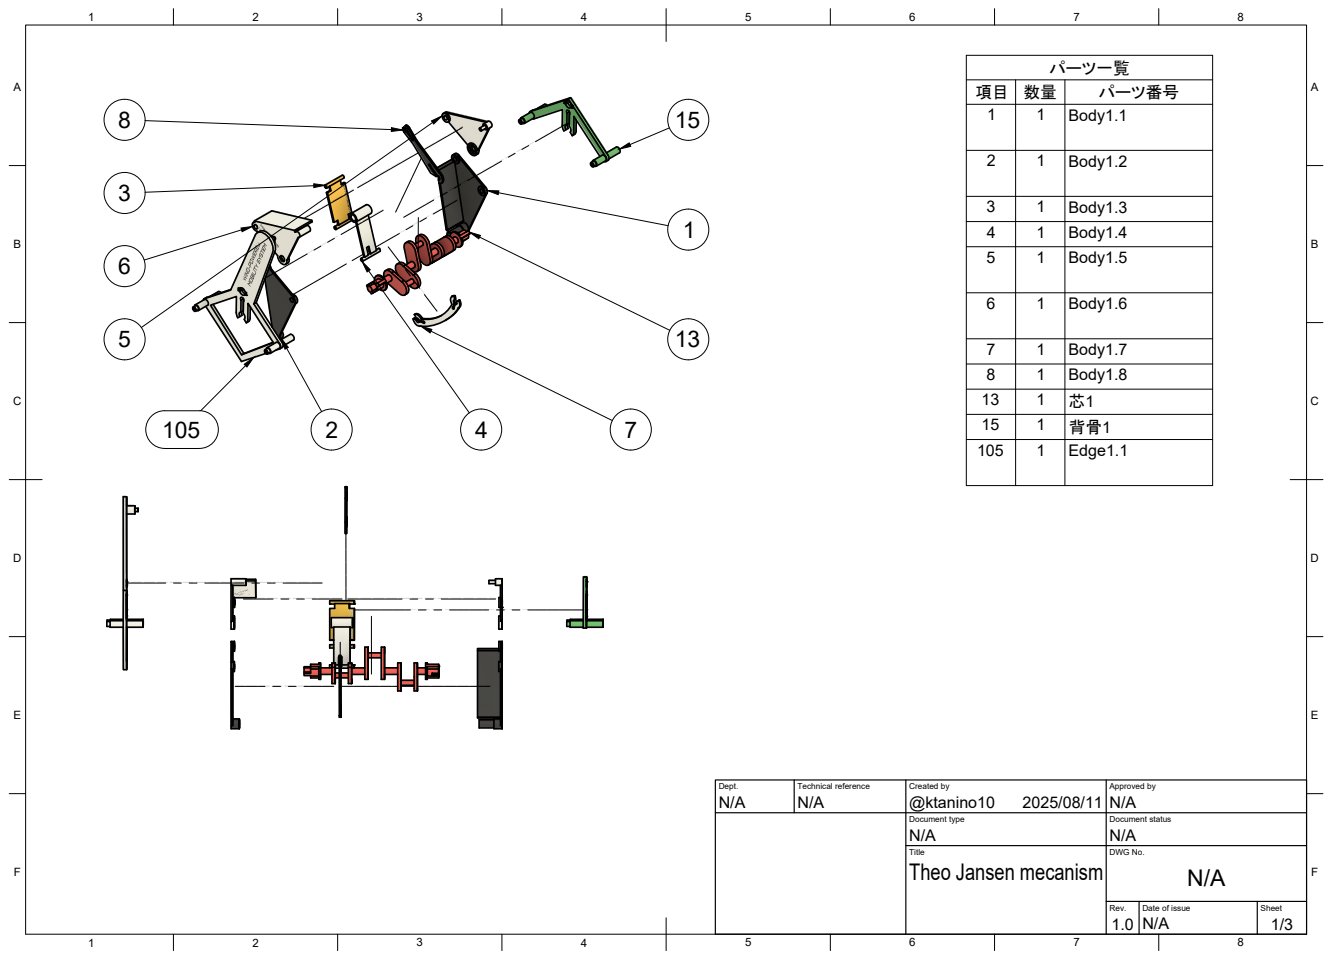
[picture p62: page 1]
Dept.; Technical reference; Created by; Approved by; Document type; Document status; Title; DWG No.; Rev.; Date of issue; Sheet; Theo Jansen mecanism; パーツ番号

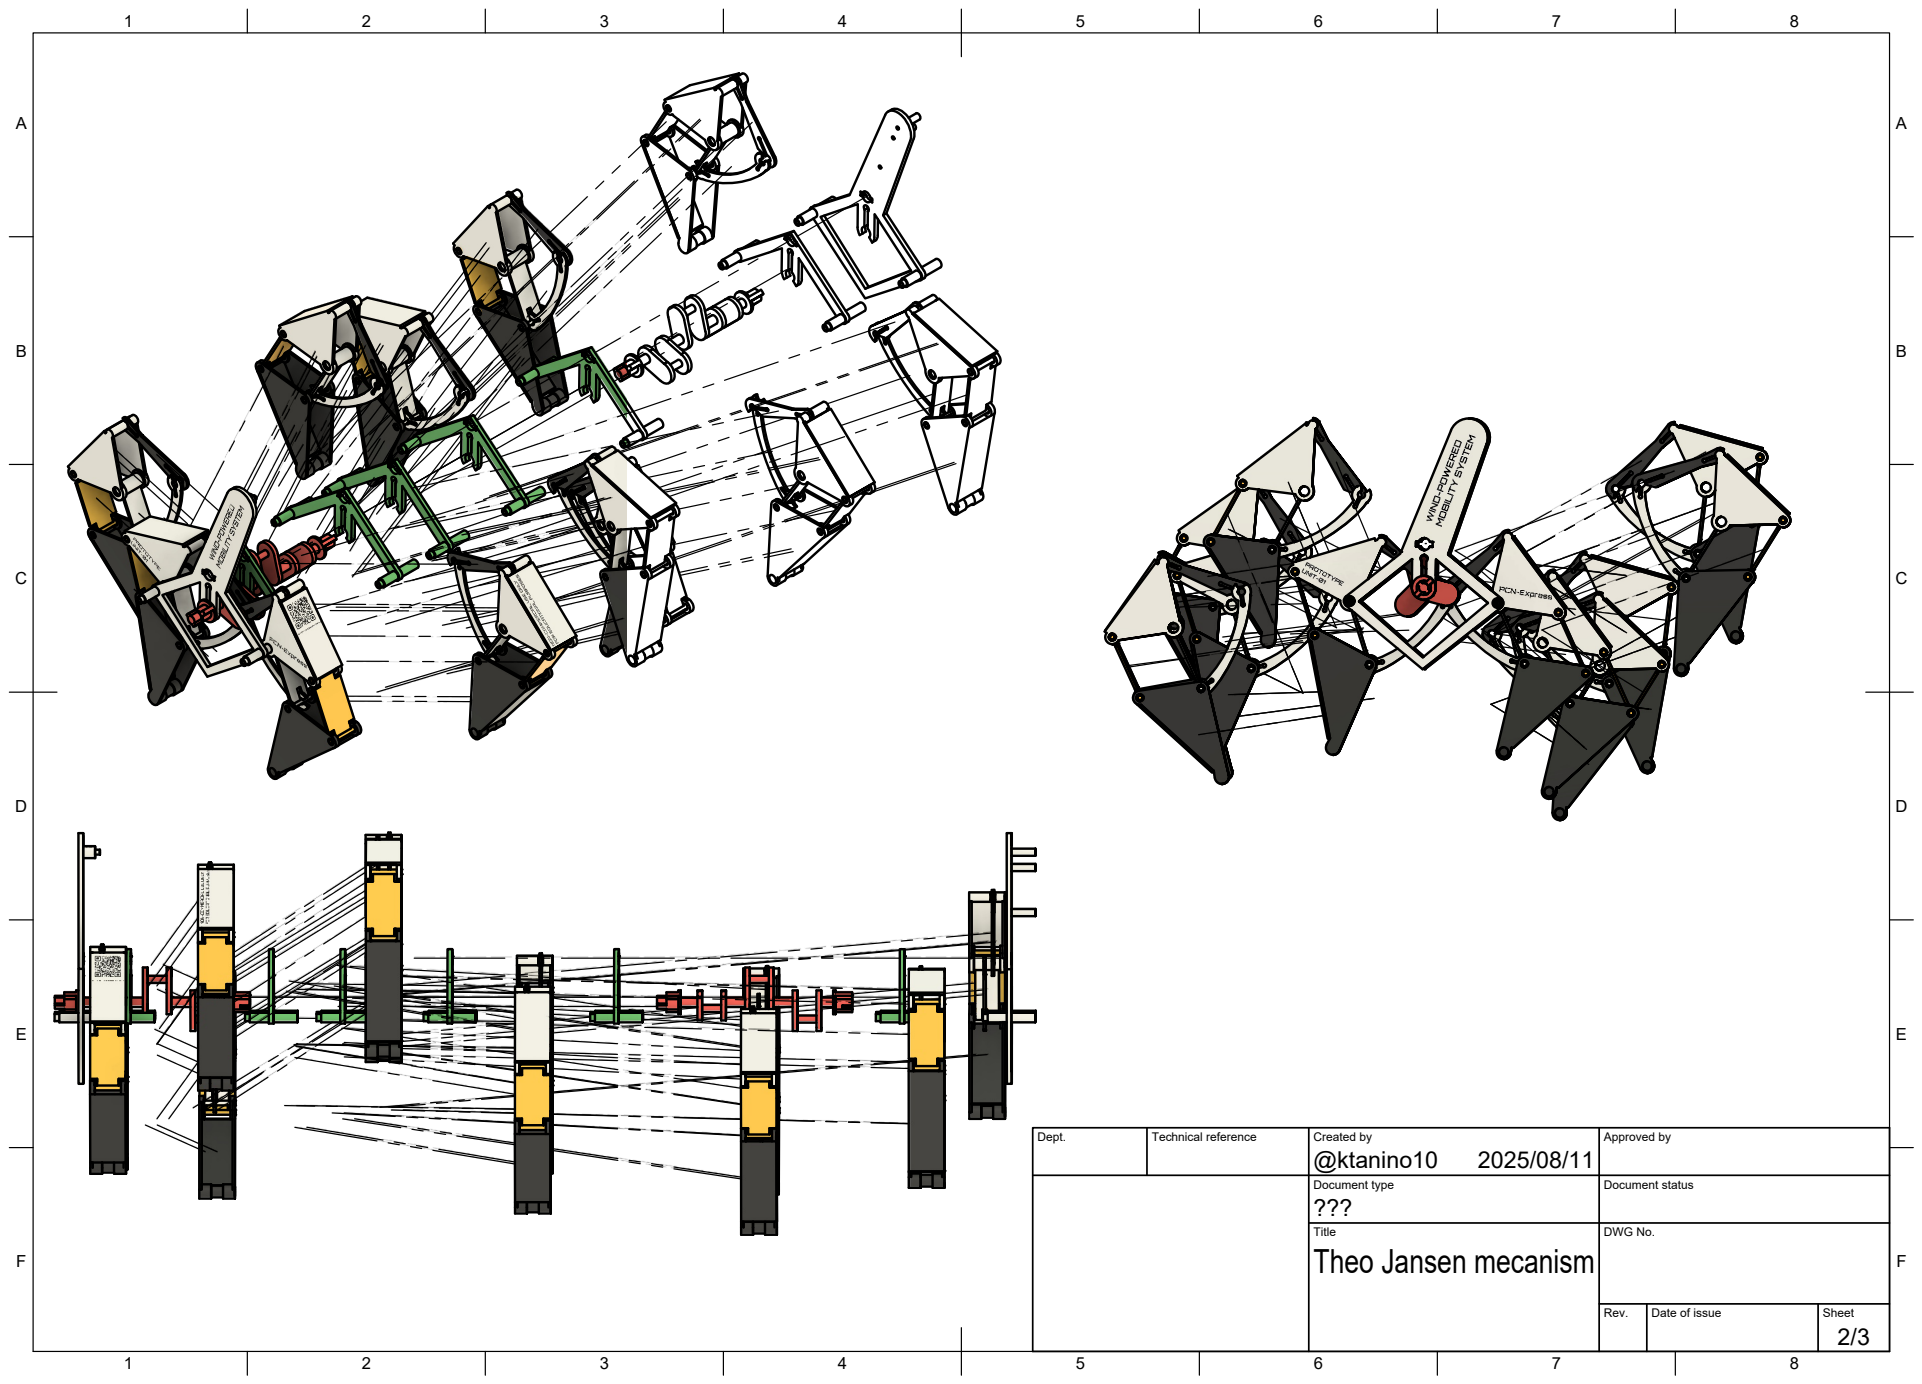
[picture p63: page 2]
Dept.; Technical reference; Created by; Approved by; Document type; Document status; Title; DWG No.

Theo Jansen mecanism

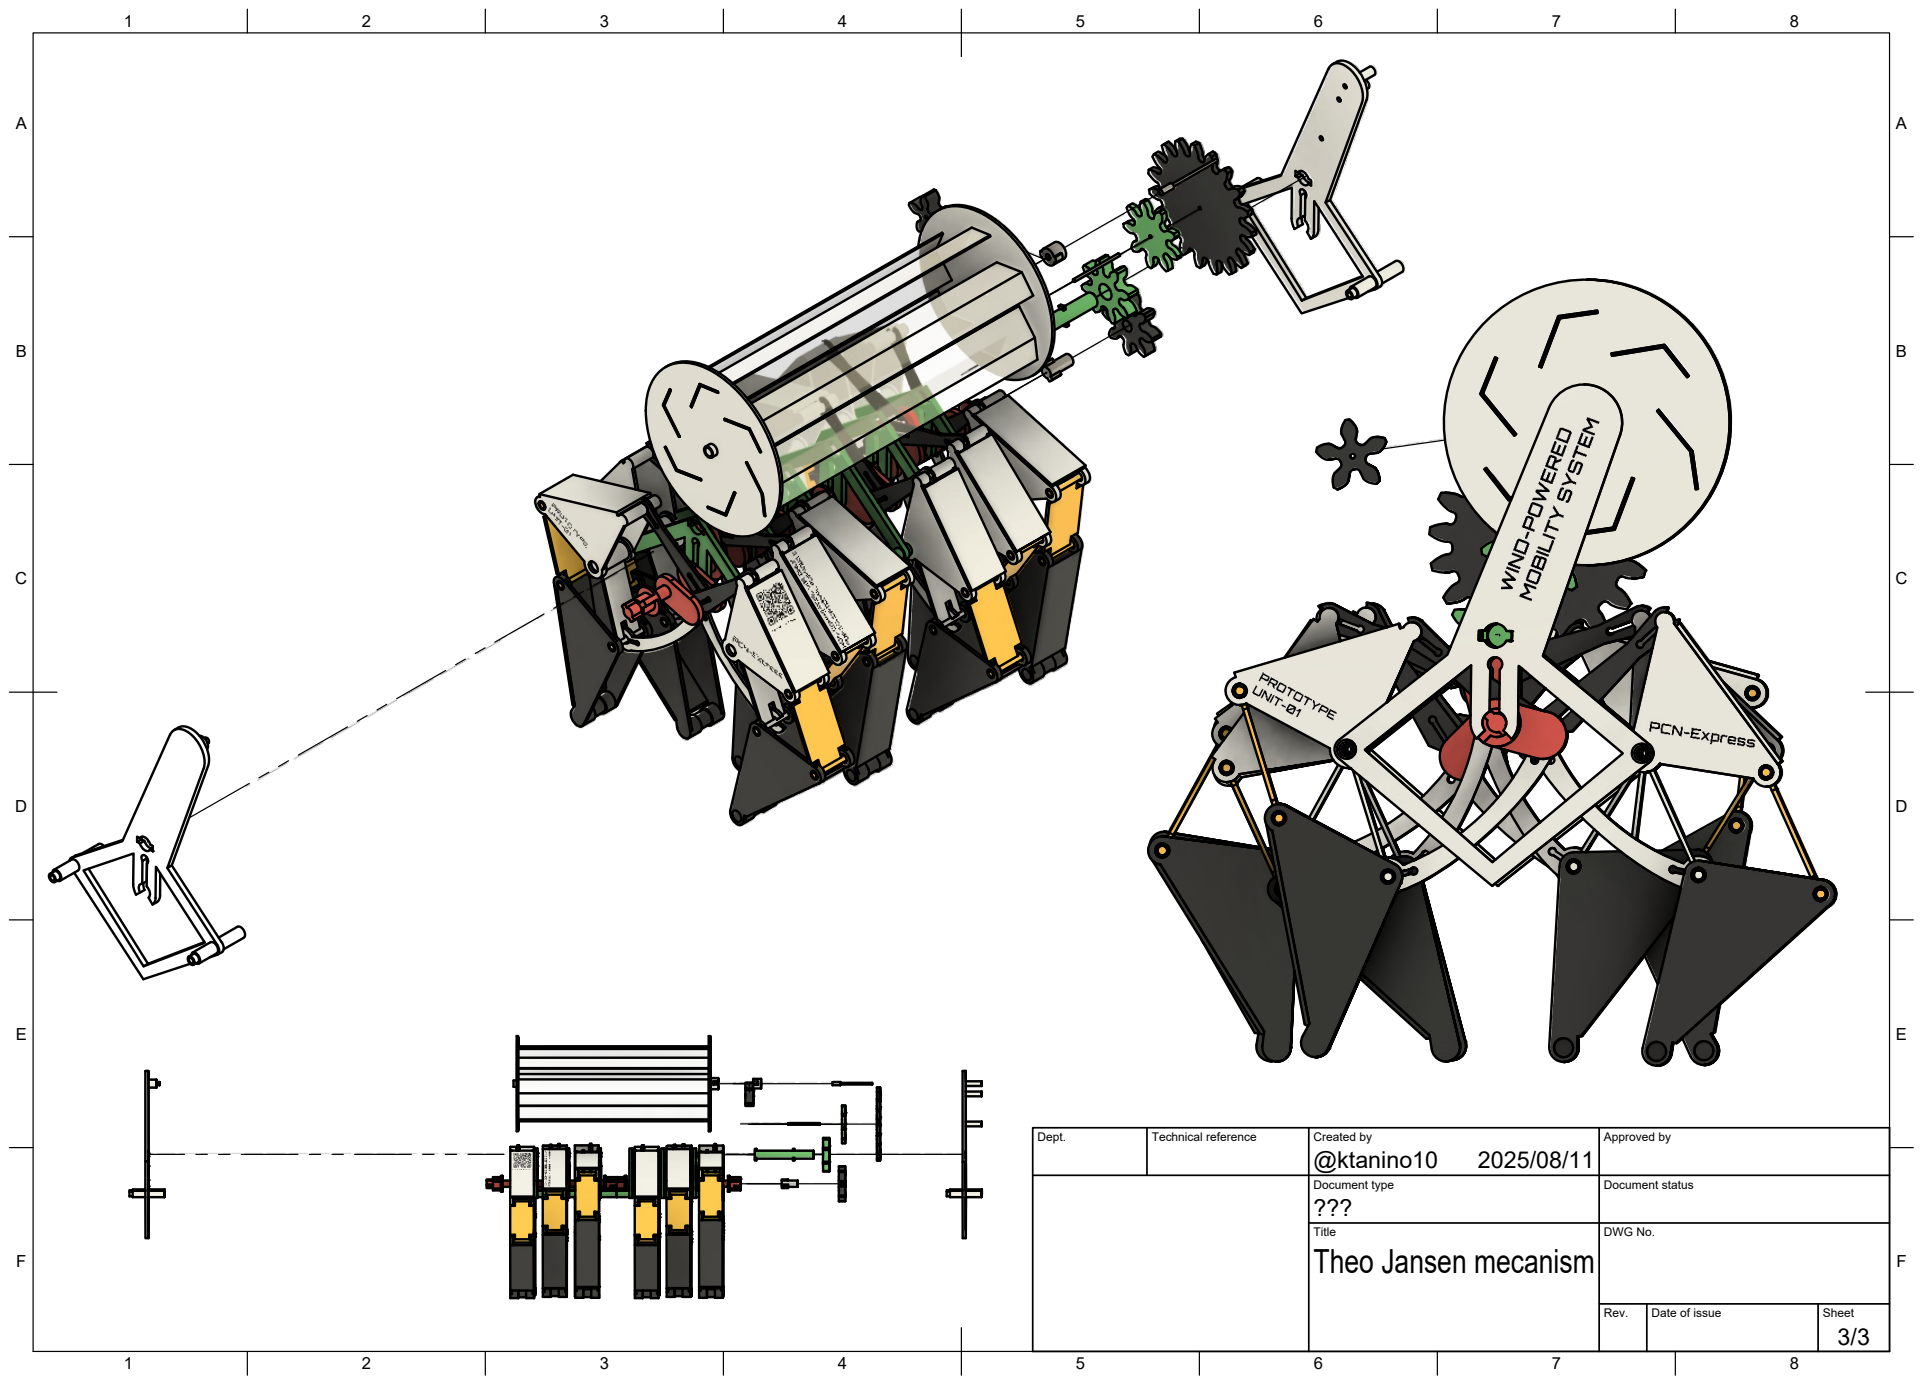
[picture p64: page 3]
Dept.; Technical reference; Created by; Approved by; Document type; Document status; Title; DWG No.

Theo Jansen mecanism

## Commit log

2025-11-03 Create stl
2025-11-03 Enhance README with project details and instructions
    Added detailed project background, repository usage, printing recommendations, and insights on the development process for the テオ・ヤンセン リノセウス prototype.
2025-11-03 Fix typo in Japanese docs and improve assembly placeholder notes
2025-11-09 Update README with assembly and simulation media
    Added assembly images, videos, and updated design references.
2026-09-26 Add Ver.3 prototype comparison, CAD, assembly guides, and walking animations
    Add three source-bound engineering concepts with native CAD, printable parts, assembly documentation, reproducible parameter search, and diagnostic walking media. Preserve physical-validation limitations and record independent review corrections.
    Copilot-Session: ca8c94d7-60fd-44b7-8b94-08a0ceb09e04
    [BOM_A.csv, BOM_B.csv, BOM_C.csv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]
2026-09-26 Add Japanese Ver.1-3 showcase and validated GitHub Pages deployment
    Build an allowlisted static site from existing photos, videos and canonical Ver.3 comparison data. Preserve first-cut limitations and add mobile/desktop playback, accessibility, metadata and subpath 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
2026-09-26 Expand Ver.1 and Ver.2 production history on Pages
    Add source-led Japanese process stages, authentic version galleries, documented revisions and explicit resource gaps. Preserve V3 engineering and performance limitations while extending the allowlist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
2026-09-26 Add source-bound Ver.3 360 viewer, assembly guide and improvement matrix
    Preserve canonical first-cut meshes, placements and limitations. Add opt-in A/B/C GLBs, part inspection, documented staged assembly and carrier-first access states, with complete static guides and so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
2026-09-26 Add bounded coupled feasibility model for Ver.3
    Keep measured wind, complete procurement and final CAD qualification explicit; add beam checks, signed contact loads, local jet screening and one synchronization alternative.
2026-09-26 Record Japanese Ver.3 feasibility gate and analysis figures
    Persist source-bound results, coupled startup and structural checks, domestic procurement evidence, and a minimal measurement proposal. Keep qualified prototype count at zero and preserve the first-c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
    [procurement_subset.csv, startup_A_high.csv, startup_A_low.csv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]
2026-09-27 Add a common commercial-dryer basis and bounded Ver.3 redesign
    Separate cold-mode reference data from Gaussian assumptions; improve five linkage dimensions and ratios while preserving failed torque/tolerance gates, exact bearing-interface limits and the frozen R2 package.
2026-09-27 Record common cold-air redesign results and optional V2 diagnostics
    Save 81 field cases, same-angle torque and margin decomposition, linkage and print-tolerance tradeoffs, 16 source-bound diagrams, exact bearing-interface findings, and an optional no-instrument V2 check. Preserve R2 and report zero qualified final prototypes.
    [comparison.csv, linkage_search.csv, startup_A_high.csv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]
2026-09-27 Publish separate source-bound materials, structure and fluid calculation notes
    Reuse the sixteen frozen commercial-r3 SVGs and comparison data without recomputing physics or changing first-cut geometry. Add A/B/C selection, readable SVG enlargement, exact loadcase and unit prov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
2026-09-27 Build one source-bound common input cartridge
    Model the locating/floating bearing holders, stock spacer and collar stack, metal D-hub test flange, all fasteners and removable paths. Verify original native CAD against private unmodified vendor references without treating nominal clamp-state interference or unknown drag as physical qualification.
2026-09-27 Add native common input cartridge and assembly evidence
    Deliver original FreeCAD/STEP, four printable STL definitions, a complete cartridge BOM, nominal solid/catalogue mass, fixed/floating ring retention and tested insertion/tool paths. Keep purchased D-clamp fit and starting resistance unverified, preserve prior research and do not redistribute vendor CAD.
    [BOM.csv, CommonInputR4.FCStd, CommonInputR4.step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]
2026-09-27 Add a source-pinned common input cartridge resource card
    Link the separately merged r4 subassembly from calculations without replacing R3 figures or first-cut models. Keep the unchanged 3.9 MB SVG opt-in at its immutable GitHub source, display source-backe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
2026-09-27 Add reviewed single-rotor module geometry and load model
    Preserve the R4 cartridge while defining one100mm rotor and absolute-load brace sizing. Correct R6-1 bearing load-point displacement transport and verify work conjugacy. Initial full review and separately authorized correction-only recheck are distinct; physical drag, air calibration, base fixation and walking remain unqualified.
2026-09-27 Preserve the rotor module and separately verified R6-1 correction
    Record native/STEP/STL, same-revision mass and conditional load data, and the distinct initial review and authorized correction-only reviewer. Preserve frozen target hashes and document the final author-only attribution correction. Physical air calibration, bearing drag, base fixation and three walking designs remain unqualified. Local handoff only; no push or publication.
    [BOM.csv, P_CAP.stl, P_CARRIER.stl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]
2026-09-27 Correct the limited-review authorization attribution
    Record coordinating-session authorization rather than end-user permission. Prose and document hashes only; reviewed code, numerical results and CAD remain unchanged. No additional review or publication.
2026-09-28 Finalize conditional r7 whole-walker engineering sources
    Integrate shared positive-drive walking geometry, real guards and assembly paths, bounded CAD validation, coupled load/work sensitivity, purchase lots and a versioned handoff contract. Preserve physi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
2026-09-28 Save verified r7-15 whole-walker engineering package
    Preserve complete A/B/C native and STEP assemblies, fine print parts, full minimum-lot bills, exact-scale sheet templates, staged assembly contracts and conditional mechanical/flow results. Record th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
    [AssemblyAccessories.FCStd, AssemblyAccessories.step, BOM.csv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]
2026-09-28 Clarify the conditional r7 print-material allowance
    Expose the FX/material assumptions and the B high-support-material case alongside the approved reference budget; no geometry or performance values changed.
2026-09-28 Bind r7 assembly paths to the ordered stage inventory
    Address independent finding R7-I1: derive every installed obstacle from the declared operation boundary, preserve explicit isolated preassembly, and lower the input module at X+4 before axial seating. Add inventory/continuity regressions and require corrective-review confirmation. CAD, physics and BOM inputs are unchanged.
2026-09-28 Save inventory-bound R7-I1 correction candidate
    Preserve the initial independent REQUEST CHANGES finding and its provenance. Record full installed-inventory path checks and the two-segment module insertion for unchanged A/B/C geometry. Independent corrective confirmation remains pending; no slicing,manufacturing or publication approval is implied.
2026-09-28 Record independent confirmation of R7-I1
    Preserve the initial REQUEST CHANGES finding and the same review context's limited CONFIRMED follow-up. Record independent inventory replay,old collision controls,new native path samples and rejection tests without changing geometry,physics or purchase data. Representative slicing remains unapproved and unperformed.
2026-09-28 Add bounded r7 slice inspection and contact-frame export
2026-09-28 Save final r7 contract and canonical contact frames
2026-09-28 Correct whole-body floor clearance and rocker pin retention
2026-09-28 Use stock rocker fasteners and a conjugate C input pair
    Freeze native and print geometry for final checks and additional C toolpath inspection; publication remains blocked pending the complete contract and checks.
    [P_CHASSIS_L.stl, P_CHASSIS_R.stl, P_COMPOUND_1.stl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]
2026-09-28 Save verified floor-correction candidate pending budget confirmation
    All non-budget package checks complete. Preserve the publication hold until the recorded reference budget is confirmed for the stock-fastener and DN-03 approach.
    [BOM.csv, Walker_A.FCStd, Walker_B.FCStd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]
2026-09-28 Record approved JPY24000 budget without changing floor2 geometry
    User approval dated2026-09-28,relayed2026-09-29. Shipping,uncertain taxes and unownedDN03 tool remain separate. No purchasing or physical qualification.
2026-09-28 Save approved floor2 publication contract and unchanged evidence
    Budget approval only:approximateJPY24000 per build,tools/shipping/uncertain taxes separate. Preserve e82a9d9 geometry,all2285 instances,121 unchanged/19 corrected STLs and all73-frame numerical results.
    [comparison.csv]
2026-09-28 Publish source-bound floor-corrected r7 showcase and visual guides
    Retain all 2285 corrected instances and schema2 ordered inventories, foot-first bench preparation, finite insertion samples and same-ID reinsertions. Add lazy exact GLBs, same-scale CGs, assembly/removal explanations, editable Blender and explicitly limited contact diagnostics. Keep first-cut and research history separate, individual budget/tool caveats and physical-performance unknowns visible.
2026-09-29 Add paired Japanese and English site and source-bound documents
    Keep Japanese root routes and share exact CAD and numerical assets. Add complete English display strings, eighteen document translations, paired documentation guides, source/hash coverage and localiz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
2026-09-29 Make Ver.3.1 the current design and archive first-cut Ver.3.0
    Route bilingual home, navigation and downloads to the source-bound floor-corrected package. Preserve archived models and media, and verify version routing without changing engineering data.
2026-09-29 Reuse real CAD checks for the current-version navigation journey
    Keep all existing rendering and control assertions while exercising them through the homepage. Avoid twelve redundant 3D startups so the full PR suite fits the unchanged CI time limit.

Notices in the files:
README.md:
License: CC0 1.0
